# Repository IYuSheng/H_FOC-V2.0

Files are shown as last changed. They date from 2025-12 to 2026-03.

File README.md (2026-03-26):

# H_FOC V2.0

<p align="center">
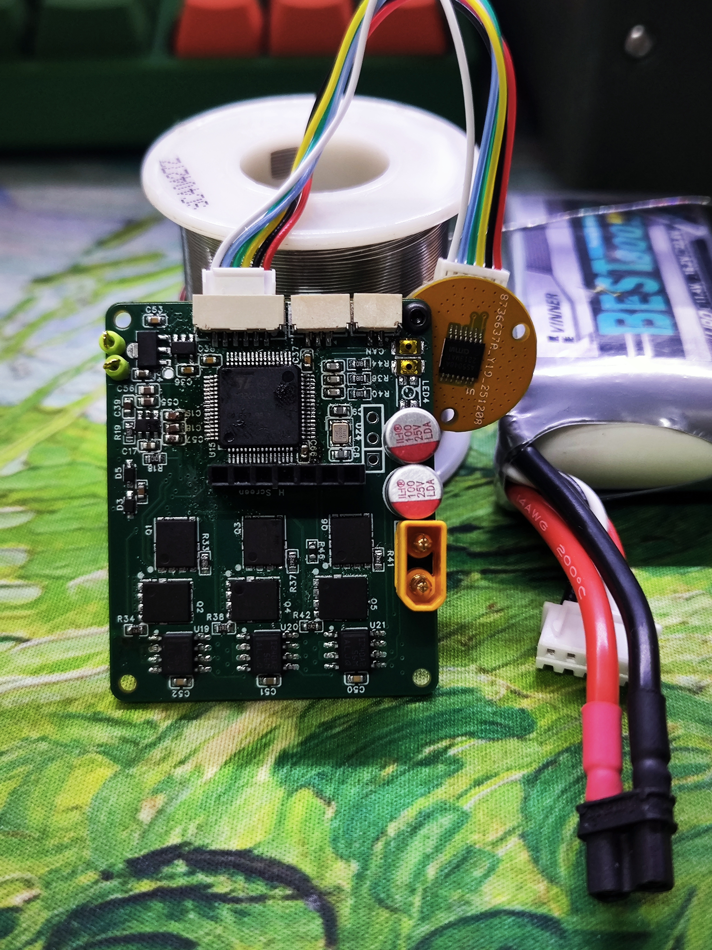
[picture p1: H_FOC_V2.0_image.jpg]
H_FOC V2.0 board render
  
</p>

<p align="center">
  面向机器人关节驱动与双关节机械臂实验平台的软硬件一体化项目
</p>

<p align="center">
  
  
  
  
</p>

<p align="center">
  <a href="#项目概览">项目概览</a> |
  <a href="#系统架构">系统架构</a> |
  <a href="#快速开始">快速开始</a> |
  <a href="#通信协议">通信协议</a> |
  <a href="#设计资料">设计资料</a>
</p>

## 项目概览

`H_FOC V2.0` 面向机器人关节电机控制场景，核心目标是构建一块可用于关节驱动、实验验证和上位机联调的 FOC 控制板，并围绕它形成一套可持续迭代的软件工具链。

从当前仓库内容来看，这个项目已经覆盖了以下几条主线：

- 基于 `STM32G431RBT6` 的电机控制固件
- 基于 `AS5048A` 的编码器闭环采样
- 基于 `CAN FD` 的主从关节通信
- 面向双关节平面机械臂的运动学、示教与重力补偿
- 基于 `Qt6` 的桌面上位机
- PCB 资料、交互式 BOM、结构模型和芯片手册归档

## 亮点特性

- `20 kHz` PWM / 电流环控制，使用 `CORDIC`、`FMAC` 等 STM32G4 外设辅助运算。
- 编码器经 `SPI2` 读取角度，并在固件中完成机械角、电角度、速度和加速度观测。
- 内置过压、欠压、过流、过温、编码器异常、采样异常等保护状态机。
- 支持 `CAN FD` 状态上报与控制指令下发，协议字段简洁清晰，适合继续扩展。
- MIT 风格控制命令已接入：目标电流、目标角度、目标速度、目标加速度、目标 jerk、刚度、阻尼、控制模式。
- `S-curve` 轨迹规划已在固件侧接入，`trapezoidal` 模式接口已预留。
- Qt 上位机已经实现双关节机械臂工作区显示、点击示教、控制模式切换和实时状态展示。
- 仓库同时保留了结构设计、BOM 和芯片资料，适合继续做硬件迭代和文档整理。

## 仓库结构

```text
H_FOC_V2.0/
|-- Code/
|   |-- H_FOC V2.1/                # 历史固件版本
|   |-- H_FOC V2.2/                # 当前主固件版本
|   |-- H_FOC_Robot_App/           # Qt6 机器人上位机
|   |-- control.py                 # 串口版控制/可视化脚本
|   `-- control_can.py             # CAN FD 版控制/可视化脚本
|-- Control_GUI/
|   `-- arm_ui/
|       `-- main.py                # RC + Serial + CAN(SLCAN) 调试界面
|-- 结构/                           # SolidWorks 结构文件
|-- 相关芯片手册/                    # 芯片资料归档
|-- InteractiveBOM_PCB1_2025-12-18.html
|-- H_FOC V2.0.docx
|-- H_FOC_V2.0_image.jpg
`-- README.md
```

### 模块索引

| 模块 | 路径 | 说明 |
| --- | --- | --- |
| 主固件 | [`Code/H_FOC V2.2`](./Code/H_FOC%20V2.2) | 推荐从这里开始，包含 FOC、编码器、CAN FD、轨迹规划与保护逻辑 |
| 旧版固件 | [`Code/H_FOC V2.1`](./Code/H_FOC%20V2.1) | 保留的历史版本，可用于对照差异 |
| Qt 上位机 | [`Code/H_FOC_Robot_App/H_FOC_Robot_App`](./Code/H_FOC_Robot_App/H_FOC_Robot_App) | 双关节机械臂界面、CAN FD 通信、运动学与控制参数配置 |
| Python CAN 工具 | [`Code/control_can.py`](./Code/control_can.py) | CAN FD 监控、示教、仿真与控制 |
| Python 串口工具 | [`Code/control.py`](./Code/control.py) | 基于 UART 文本协议的控制与可视化 |
| 调试 GUI | [`Control_GUI/arm_ui/main.py`](./Control_GUI/arm_ui/main.py) | RC + Serial + SLCAN 联调工具 |
| 交互式 BOM | [`InteractiveBOM_PCB1_2025-12-18.html`](./InteractiveBOM_PCB1_2025-12-18.html) | 浏览器可直接打开 |
| 结构模型 | [`结构`](./结构) | 结构件、座子和测试台架模型 |
| 芯片资料 | [`相关芯片手册`](./相关芯片手册) | MCU、编码器等资料归档 |
| 设计说明 | [`H_FOC V2.0.docx`](./H_FOC%20V2.0.docx) | 板卡引脚与说明文档 |

## 固件概览

主固件位于 [`Code/H_FOC V2.2`](./Code/H_FOC%20V2.2)，从代码可以确认它的关键特征如下：

| 项目 | 内容 |
| --- | --- |
| 主控 MCU | `STM32G431RBT6` |
| 系统主频 | `170 MHz` |
| PWM 频率 | `20 kHz` |
| 编码器 | `AS5048A` |
| 总线 | `FDCAN1` |
| 调试串口 | `USART3` |
| 工程文件 | `MDK-ARM/H_FOC V2.0.uvprojx` |
| CubeMX 文件 | `H_FOC V2.0.ioc` |

默认参数中可读到以下安全和控制边界：

| 项目 | 默认值 |
| --- | --- |
| 母线电压限制 | `30.0 V` |
| 最大相电流 | `5.5 A` |
| 欠压阈值 | `9.0 V` |
| 过温阈值 | `60.0 °C` |
| 电机极对数 | `11` |
| 机械角度保护范围 | `-170° ~ 70°` |

### 固件主入口

- 参数配置：[`Code/H_FOC V2.2/APP/Config.h`](./Code/H_FOC%20V2.2/APP/Config.h)
- 系统入口：[`Code/H_FOC V2.2/Core/Src/main.c`](./Code/H_FOC%20V2.2/Core/Src/main.c)
- 初始化：[`Code/H_FOC V2.2/APP/FOC_Init.c`](./Code/H_FOC%20V2.2/APP/FOC_Init.c)
- 编码器驱动：[`Code/H_FOC V2.2/APP/foc_encoder.c`](./Code/H_FOC%20V2.2/APP/foc_encoder.c)
- 控制主逻辑：[`Code/H_FOC V2.2/APP/foc_control.c`](./Code/H_FOC%20V2.2/APP/foc_control.c)
- 通信封装：[`Code/H_FOC V2.2/MID/foc_communication.c`](./Code/H_FOC%20V2.2/MID/foc_communication.c)
- CAN FD 协议：[`Code/H_FOC V2.2/Core/Inc/fdcan.h`](./Code/H_FOC%20V2.2/Core/Inc/fdcan.h)

## 上位机与工具链

### Qt6 机器人上位机

路径：[`Code/H_FOC_Robot_App/H_FOC_Robot_App`](./Code/H_FOC_Robot_App/H_FOC_Robot_App)

当前功能：

- `Qt 6.5+`
- `Qt Widgets + Qt SerialPort`
- 双关节机械臂工作区可视化
- 点击画布设置末端目标点
- 实时显示目标位置、当前姿态、关节角速度、电流与通信状态
- 提供 `normal / trapezoidal / s_curve` 控制模式选项
- 当前固件侧重点接入的是 `normal / s_curve`
- 可配置刚度、阻尼、速度、加速度、jerk

关键配置入口：

- [`Code/H_FOC_Robot_App/H_FOC_Robot_App/core/appconfig.h`](./Code/H_FOC_Robot_App/H_FOC_Robot_App/core/appconfig.h)

## 通信协议

### CAN FD 协议摘要

当前固件与上位机使用的协议要点如下：

- 标准 `11-bit CAN ID`
- ID 组织方式：`(src << 8) | (dst << 4) | type`
- 主节点 ID：`0`
- 默认关节节点：`1 / 2`
- 广播地址：`0x0F`
- 仲裁段速率：`1 Mbps`
- 数据段速率：`2 Mbps`
- 定点缩放比例：`1e-5`

### 状态帧 `STATUS`

| 字段 | 类型 |
| --- | --- |
| position | `int32` |
| velocity | `int32` |
| current | `int32` |
| temperature | `int32` |
| acceleration | `int32` |

### 控制帧 `CONTROL`

| 字段 | 类型 |
| --- | --- |
| target_current | `int32` |
| target_angle | `int32` |
| target_velocity | `int32` |
| target_acceleration | `int32` |
| target_jerk | `int32` |
| stiffness | `int32` |
| damping | `int32` |
| control_mode | `uint8` |

### UART 文本命令

固件串口解析逻辑当前可识别以下文本命令：

- `target_position:<float>`
- `target_speed:<float>`
- `current_q:<float>`
- `target_q:<float>`

这使得在没有 CAN FD 的情况下，仍然可以通过串口完成基础联调。

## 快速开始

### 环境准备

建议准备以下工具链：

- `Keil MDK` 或可兼容当前工程的 ARM 编译环境
- `STM32CubeMX`，用于查看或再生成外设配置
- `Qt 6.5+`
- CAN FD 转接设备，或支持 `SLCAN` 的串口桥接设备

### 固件构建

1. 打开 [`Code/H_FOC V2.2/MDK-ARM/H_FOC V2.0.uvprojx`](./Code/H_FOC%20V2.2/MDK-ARM/H_FOC%20V2.0.uvprojx)
2. 根据硬件修改 [`Code/H_FOC V2.2/APP/Config.h`](./Code/H_FOC%20V2.2/APP/Config.h)
3. 编译并下载到 `STM32G431RBT6`
4. 如需查看外设配置，可打开 [`Code/H_FOC V2.2/H_FOC V2.0.ioc`](./Code/H_FOC%20V2.2/H_FOC%20V2.0.ioc)

### Qt 上位机构建

```powershell
cd "Code/H_FOC_Robot_App/H_FOC_Robot_App"
cmake -S . -B build
cmake --build build --config Release
```

依赖：

- `Qt 6.5+`
- `Qt SerialPort`

## 配置入口

如果你要改默认参数，通常会从这些文件开始：

| 场景 | 文件 |
| --- | --- |
| 固件控制参数 | [`Code/H_FOC V2.2/APP/Config.h`](./Code/H_FOC%20V2.2/APP/Config.h) |
| Qt 上位机默认通道和控制参数 | [`Code/H_FOC_Robot_App/H_FOC_Robot_App/core/appconfig.h`](./Code/H_FOC_Robot_App/H_FOC_Robot_App/core/appconfig.h) |

## 设计资料

保留了较完整的研发资料入口：

- 板卡外观图：[`H_FOC_V2.0_image.jpg`](./H_FOC_V2.0_image.jpg)
- 交互式 BOM：[`InteractiveBOM_PCB1_2025-12-18.html`](./InteractiveBOM_PCB1_2025-12-18.html)
- 结构模型：[`结构`](./结构)
- 芯片手册：[`相关芯片手册`](./相关芯片手册)
- 设计说明：[`H_FOC V2.0.docx`](./H_FOC%20V2.0.docx)

<details>
<summary>展开查看板卡主要引脚摘要</summary>

- ADC 采样：`PC0 / PC1 / PC2 / PC3` = `VA / VB / VC / VBUS`
- 电流采样：`PA0 / PA1 / PA2` = `IA / IB / IC`
- 温度采样：`PC4`
- 三相驱动高端：`PC6 / PC7 / PC8`
- 三相驱动低端：`PC10 / PC11 / PC12`
- 编码器：`PB12 / PB13 / PB14 / PB15`
- 调试 DAC：`PA4 / PA5`
- 调试串口：`PB10 / PB11`
- 屏幕接口：`PB3 / PB5 / PB6 / PB7 / PA15`
- CAN：`PB8 / PB9`
- 按键：`PA8 / PA9`
- 三色灯：`PB0 / PB1 / PB2`

</details>

## 安全提示

涉及电机、功率板和机械臂时，建议至少注意以下几点：

- 首次上电时使用受限电源或降低电压。
- 先确认编码器方向、零位和关节限位是否正确。
- 在低速、空载或脱开机械结构的状态下先验证闭环。
- 修改电流、电压和刚度参数前，先确认硬件承受范围。
- 在真实机械臂联调时，避免直接在满量程和无软限位保护下运行。

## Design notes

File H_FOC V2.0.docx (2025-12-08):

# H_FOC V2.0

## 1. 引脚定义

(1) ADC采样

PC0、PC1、PC2、PC3 : VA、VB、VC、VBUS

PA0、PA1、PA2 : IA、IB、IC

PC4 : R_Temperature

(2) 驱动

高端:PC6、PC7、PC8 : HA、HB、HC

低端:PC10、PC11、PC12 : LA、LB、LC

(3) 编码器

PB12、PB13、PB14、PB15 : Encoder_CS、Encoder_SCK、Encoder_MISO、Encoder_MOSI

(4) 调试DAC

PA4、PA5 : DAC1、DAC2

(5) 调试串口

PB10、PB11 : UART3_TX、UART_RX

(6) 屏幕

PB3、PB5、PB6、PB7、PA15 : Screen_SCK、Screen_MOSI、Screen_DC、Screen_RES、Screen_CS

(7) CAN通讯

PB8、PB9 : FDCAN_RX、FDCAN_TX

(8) 按键

PA8、PA9 : KEY_1、KEY_2

(9) 三色灯

PB0、PB1、PB2 : Blue、Green、Red

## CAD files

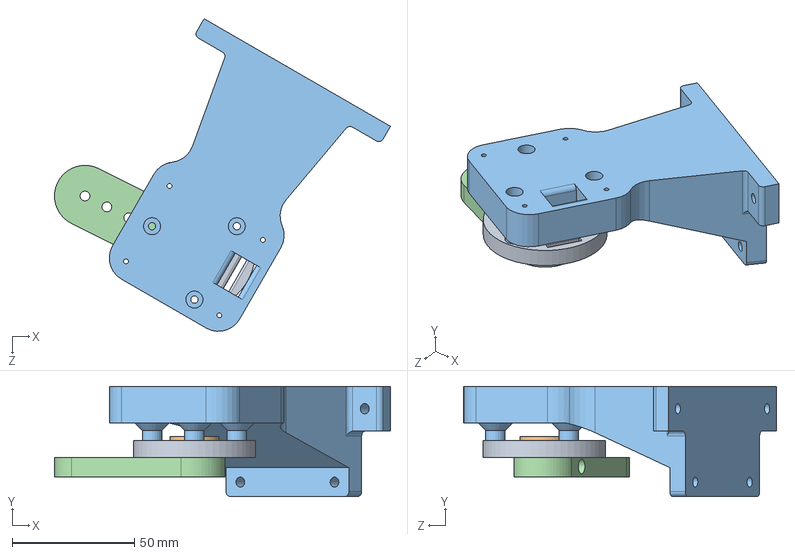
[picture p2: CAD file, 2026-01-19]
结构/电机座子/电机座子.SLDASM
137.4 x 45.0 x 127.8 mm
电机转接器
编码器板
电机驱动板连接器
测试负载连杆

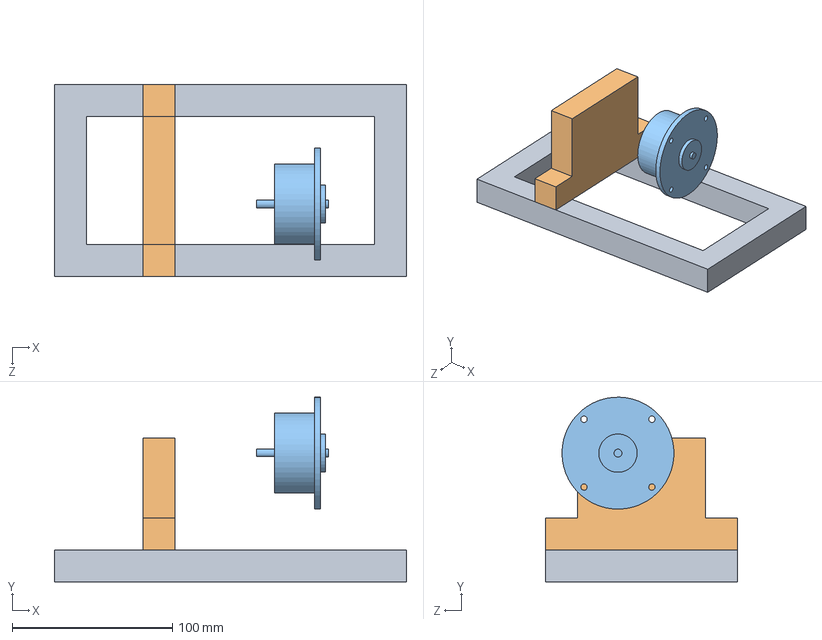
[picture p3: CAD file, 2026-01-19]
结构/电机测试台架/测试台架装配体.SLDASM
220.0 x 115.4 x 120.0 mm
台架底座
电机支架底座
磁粉制动器

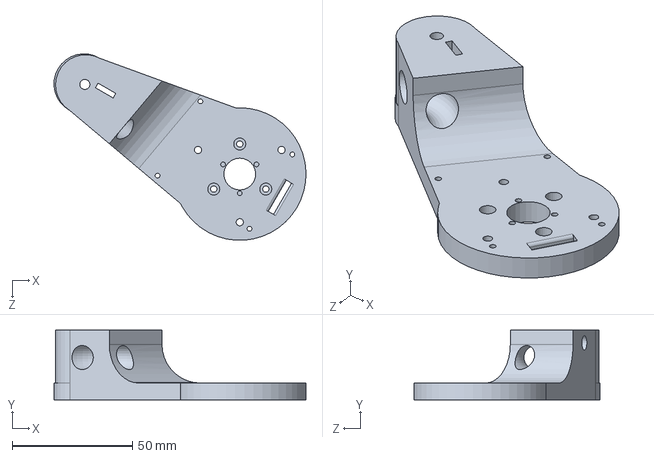
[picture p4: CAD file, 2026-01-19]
结构/电机座子/第二电机测试座.SLDPRT
104.6 x 29.0 x 77.3 mm

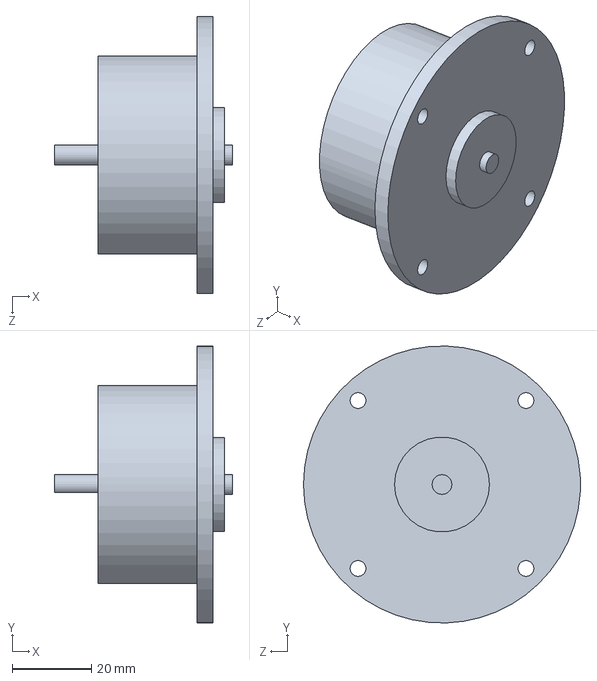
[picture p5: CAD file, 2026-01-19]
结构/电机测试台架/磁粉制动器.SLDPRT
45.0 x 70.0 x 70.0 mm

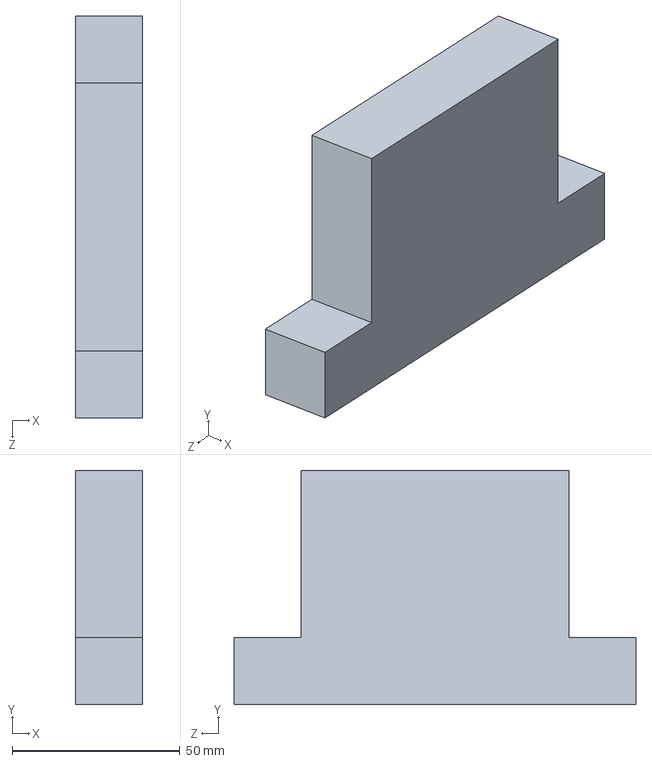
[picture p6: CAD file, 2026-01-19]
结构/电机测试台架/电机支架底座.SLDPRT
20.0 x 70.0 x 120.0 mm

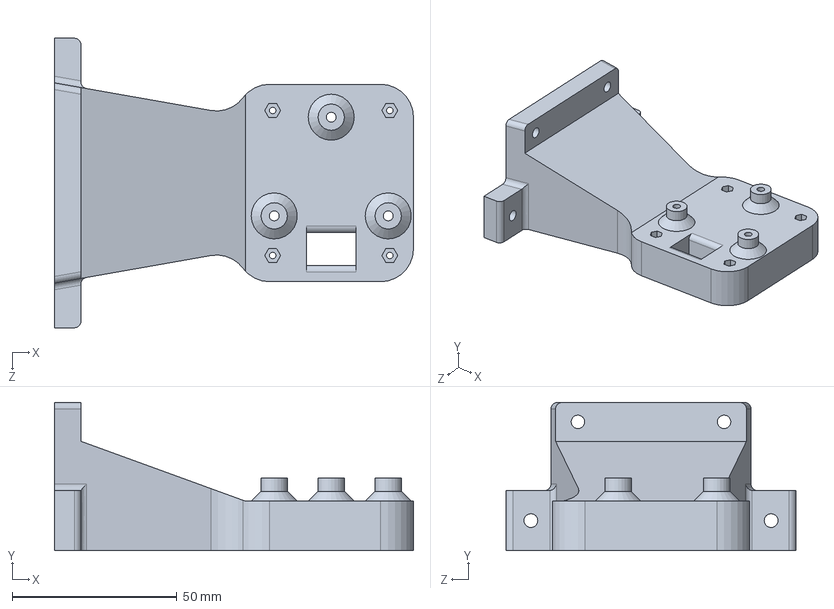
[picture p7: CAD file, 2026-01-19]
结构/电机座子/电机驱动板连接器.SLDPRT
109.1 x 45.0 x 88.0 mm

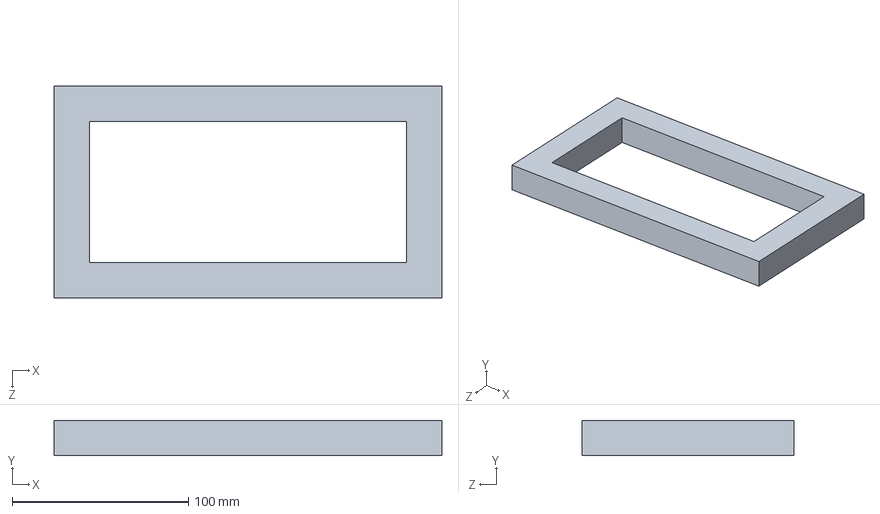
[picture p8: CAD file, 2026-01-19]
结构/电机测试台架/台架底座.SLDPRT
220.0 x 20.0 x 119.9 mm

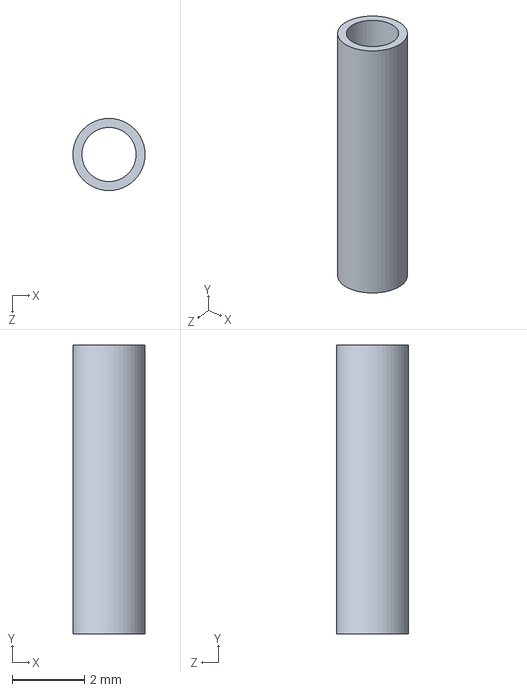
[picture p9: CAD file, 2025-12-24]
结构/电机座子/驱动器支撑柱.SLDPRT
2.00 x 8.00 x 2.00 mm

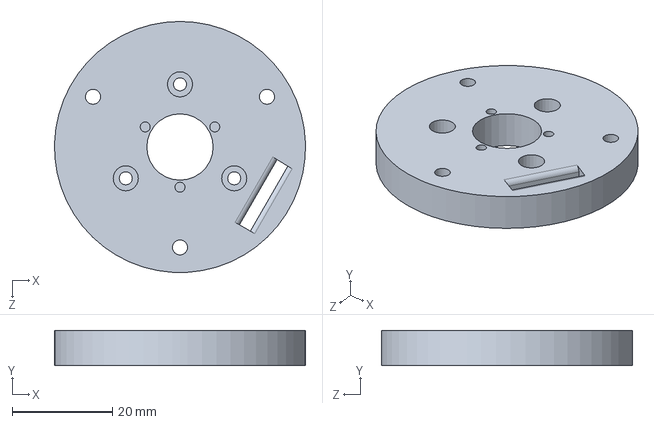
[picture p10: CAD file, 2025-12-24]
结构/电机座子/电机转接器.SLDPRT
50.0 x 7.00 x 50.0 mm

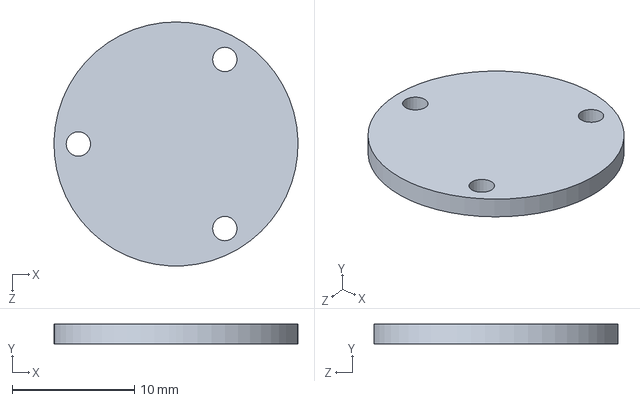
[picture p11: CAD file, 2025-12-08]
结构/电机座子/编码器板.SLDPRT
20.0 x 1.60 x 20.0 mm

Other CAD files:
结构/电机座子/测试负载连杆.SLDPRT

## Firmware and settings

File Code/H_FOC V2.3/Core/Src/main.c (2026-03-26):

#include "main.h"

Motor_Control_t motor_ctrl = {
    .foc_state =  FOC_STATE_INIT,
    .fault_type = MOTOR_FAULT_NONE,
    .temp_max = OVER_TEMPERATURE_THRESH,    // 过温阈值
    .vbus_max = VOLTAGE_LIMIT,              // 过压阈值
    .vbus_min = UNDER_VOLTAGE_THRESH,       // 欠压阈值
    .current_max = CURRENT_LIMIT,            // 过流阈值
    .angle_max = 90.0f,                      // 最大角度阈值（°/s）
    .angle_min = -190.0f                     // 最小角度阈值（°/s）
};

encoder_status_t enc_status; // 编码器状态变量

/**
  * @brief  The application entry point.
  * @retval int
  */
int main(void)
{
    // 初始化FOC相关外设
    FOC_Init();
    
    while(1)
    {
      /* ------------------ FOC状态机 ------------------ */
      switch(motor_ctrl.foc_state)
      {
        case FOC_STATE_INIT:  /* 电机初始化 */
          // 初始化编码器
          enc_status = encoder_init();
          foc_start_init();
          if(enc_status != ENCODER_STATUS_OK)
          {
            motor_ctrl.fault_type = FAULT_ENCODER;
            motor_ctrl.foc_state = FOC_STATE_FAULT;
          }
          // 开启FOC中断
          foc_start();
          motor_ctrl.foc_state = FOC_STATE_RUNNING;
          break;

        case FOC_STATE_RUNNING: /* 电机运行态 */
          // 设置外部控制参数
          foc_control_set();

          break;

        case FOC_STATE_FAULT: /* 电机故障态 */
          // 停止PWM输出
          bsp_pwm_stop();
          switch(motor_ctrl.fault_type)
          {
            case FAULT_OVER_VOLTAGE:
              debug_log("[ERROR] OVER_VOLTAGE");
              break;
              
            case FAULT_UNDER_VOLTAGE:
              debug_log("[ERROR] UNDER_VOLTAGE");
              break;
              
            case FAULT_OVER_CURRENT:
              debug_log("[ERROR] OVER_CURRENT");
              break;
              
            case FAULT_ENCODER:
              debug_log("[ERROR] ENCODER_ERROR");
              break;
              
            case FAULT_OVER_TEMPERATURE:
              debug_log("[ERROR] OVER_TEMPERATURE");
              break;

            case FAULT_I_SAMPLING_ERROR:
              debug_log("[ERROR] I_SAMPLING_ERROR");
              break;

            case FAULT_ENCODER_ANGLE:
              debug_log("[ERROR] ENCODER_ANGLE_ERROR");
              break;
              
            case MOTOR_FAULT_NONE:
              // 待添加恢复机制

              break;
            default:
              debug_log("[ERROR] UNKNOWN_ERROR");
              break;
          }
          motor_ctrl.foc_state = FOC_STATE_STOP;
          break;

        case FOC_STATE_STOP:  /* 电机停止态 */

          break;

        default:
          break;
      }

      /* --------------- 定时处理任务 --------------- */
      if(foc_task.task_update_vbus)
      {
        foc_task.task_update_vbus = 0;
        get_foc_bus_voltage();
      }
      if(foc_task.task_update_three_phase_voltage)
      {
        foc_task.task_update_three_phase_voltage = 0;
        update_Three_phase_voltage();
      }
      if(foc_task.task_update_temperature)
      {
        foc_task.task_update_temperature = 0;
        update_mosfet_temperature();
      }
      if(foc_task.task_sys_common)
      {
        foc_task.task_sys_common = 0;
        // CAN数据发送至主节点
        CAN_ReportStatus();
        // CAN数据处理
        CAN_Process();
        // foc打印调试任务
        foc_debug();
      }

      /* --------------- 异常状态检测 --------------- */
     if(foc_voltage_data.vbus > motor_ctrl.vbus_max)
     {
       motor_ctrl.fault_type = FAULT_OVER_VOLTAGE;
       if(motor_ctrl.foc_state == FOC_STATE_RUNNING)
       motor_ctrl.foc_state = FOC_STATE_FAULT;
     }
     if(foc_voltage_data.vbus < motor_ctrl.vbus_min)
     {
       motor_ctrl.fault_type = FAULT_UNDER_VOLTAGE;
       if(motor_ctrl.foc_state == FOC_STATE_RUNNING)
       motor_ctrl.foc_state = FOC_STATE_FAULT;
     }
     
     if(foc_current_data.ia > motor_ctrl.current_max
     || foc_current_data.ib > motor_ctrl.current_max
     || foc_current_data.ic > motor_ctrl.current_max)
     {
       motor_ctrl.fault_type = FAULT_OVER_CURRENT;
       if(motor_ctrl.foc_state == FOC_STATE_RUNNING)
       motor_ctrl.foc_state = FOC_STATE_FAULT;
     }
     if(foc_voltage_data.temp > motor_ctrl.temp_max)
     {
       motor_ctrl.fault_type = FAULT_OVER_TEMPERATURE;
       if(motor_ctrl.foc_state == FOC_STATE_RUNNING)
       motor_ctrl.foc_state = FOC_STATE_FAULT;
     }
     if(foc_current_data.ia + foc_current_data.ib + foc_current_data.ic > 10.0f
     || foc_current_data.ia + foc_current_data.ib + foc_current_data.ic < -10.0f)
     {
       motor_ctrl.fault_type = FAULT_I_SAMPLING_ERROR;
       if(motor_ctrl.foc_state == FOC_STATE_RUNNING)
       motor_ctrl.foc_state = FOC_STATE_FAULT;
     }
    //  if(encoder_data.mechanical_angle > motor_ctrl.angle_max || encoder_data.mechanical_angle < motor_ctrl.angle_min)
    //  {
    //    motor_ctrl.fault_type = FAULT_ENCODER_ANGLE;
    //    if(motor_ctrl.foc_state == FOC_STATE_RUNNING)
    //    motor_ctrl.foc_state = FOC_STATE_FAULT;
    //  }
    }
}

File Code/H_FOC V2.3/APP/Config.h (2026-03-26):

#ifndef __CONFIG_H
#define __CONFIG_H

#include <arm_math.h>

// --------------------------- 模式选项 --------------------------
#define DEBUG_MODE  1     // 打开仿真波形打印

// -------------------------- 电源与硬件限制 --------------------------
#define VOLTAGE_LIMIT           30.0f   // 直流母线电压限制 (V)
#define CURRENT_LIMIT           5.5f    // 最大相电流限制 (A)
#define UNDER_VOLTAGE_THRESH    9.0f   // 欠压保护阈值 (V)
#define OVER_TEMPERATURE_THRESH 60.0f   // 过温保护阈值 (摄氏度)

// -------------------------- 电机参数 -------------------------- 
#define MOTOR_POLE_PAIRS     11       // 电机极对数
#define MOTOR_RESISTANCE     0.338f    // 相电阻 (欧姆)
#define MOTOR_INDUCTANCE     0.000113f  // 相电感 (H)
#define MOTOR_INDUCTANCE_Lq  0.000140f // q轴电感 (H)
#define MOTOR_INDUCTANCE_Ld  0.000086f // d轴电感 (H)
#define MOTOR_FLUX_LINKAGE   0.002481f   // 磁链 (Wb)

#define MOTOR_LOW             -53.7f * PI / 180.0f   // 物理层面上的电机最低位置

// -------------------------- FOC控制参数 --------------------------
#define PWM_FREQ            20000.0f   // PWM频率 (Hz)，需与定时器配置匹配
#define HALF_PWM_FREQ       PWM_FREQ * 0.5f   // PWM频率 (Hz)，需与定时器配置匹配
#define PWM_PERIOD_S        1.0f / PWM_FREQ  // PWM周期（单位：s），与PWM_FREQ对应：T = 1/F
#define SVPWM_VOLT_COEF     (2.0f / sqrtf(3.0f)) // SVPWM基本矢量幅值系数（母线电压相关，固定值）
#define DEAD_TIME_S         (170e-9f)       // 死区时间 170ns

// -------------------------- PI调节器参数 --------------------------
// 电流环PI
#define CURRENT_LOOP_COUNT        PWM_FREQ
#define CURRENT_LOOP_DT           (1.0f / CURRENT_LOOP_COUNT)  // 电流环调用周期 (单位：s)
#define I_D_P_GAIN                (MOTOR_INDUCTANCE_Ld / (3 * PWM_PERIOD_S)) //Kp = Ld / (3*Ts)
#define I_Q_P_GAIN                (MOTOR_INDUCTANCE_Lq / (3 * PWM_PERIOD_S)) //Kp = Lq / (3*Ts)
#define I_I_GAIN                  ((MOTOR_RESISTANCE / (3 * PWM_PERIOD_S)) * CURRENT_LOOP_DT) //KI = (Rs / (3*Ts)) * Ts(减小一个乘法)
#define CURRENT_LOOP_BANDWIDTH    (I_Q_P_GAIN / (2 * PI * MOTOR_INDUCTANCE_Lq))      // 电流环带宽 (Hz) 1061
#define I_I_LIMIT                 0.2f

// 速度环PI
#define SPEED_LOOP_TIME     1000.0f
#define SPEED_LOOP_COUNT    (PWM_FREQ / SPEED_LOOP_TIME)
#define SPEED_LOOP_DT       (1.0f / SPEED_LOOP_TIME)      // 速度环调用周期 (单位：s)
#define SPEED_P_GAIN        0.0002f
#define SPEED_I             0.00001f
#define SPEED_I_GAIN        (SPEED_I * SPEED_LOOP_DT) //KI = Ki * Ts(减小一个乘法)
#define SPEED_I_LIMIT       0.05f
#define SPEED_OUT_LIMIT     1.0f

// 位置环PID
#define POSITION_LOOP_TIME   1000.0f  // 位置环调用频率 (1000Hz)
#define POSITION_LOOP_COUNT  (PWM_FREQ / POSITION_LOOP_TIME)
#define POSITION_LOOP_DT    (1.0f / POSITION_LOOP_TIME) // 位置环调用周期 (单位：s)
#define POSITION_P_GAIN     0.1f
#define POSITION_I          0.0f
#define POSITION_I_GAIN     (POSITION_I * POSITION_LOOP_DT) //KI = Ki * Ts(减小一个乘法)
#define POSITION_D_GAIN     0.002f
#define POSITION_I_LIMIT    0.08f
#define POSITION_OUT_LIMIT  4.0f
#define POSITION_KV         8.0f
#define POSITION_W_MAX      600.0f

// -------------------------- 电流采样配置 --------------------------
#define ADC_REF_VOLTAGE     3.3f    // ADC参考电压 (V)
#define ADC_MAX_VALUE       4095.0f    // ADC分辨率 (例如：12位ADC为4095，0-4095)
#define INA240_GAIN         50.0f   // 电流采样运放增益
#define V_REF               1.65f    // REF1 引脚电压3.3V，单位：V
#define R_Current           0.006f    // 采样电阻阻值

// -------------------------- 电压采样配置 --------------------------
#define R_Voaltage_1  20.0f   // 20KΩ
#define R_Voaltage_2  2.2f    // 2.2KΩ

// -------------------------- 常用常量及中间变量定义 --------------------------
#define _PI         PI
#define _2PI        (2.0f * PI)
#define _PI_2       (PI / 2.0f)
#define _2_PI       (1.0f / (2.0f * PI))
#define _60_angle   (2.0f * PI / 6.0f)  // 60度对应的弧度
#define _SQRT3      1.732050807568877f
#define _SQRT3_2    0.866025403784439f  // sqrt(3)/2
#define _1_SQRT3    0.577350269189626f  // 1/sqrt(3)
#define _2_SQRT3    1.154700538379252f  // 2/sqrt(3)
#define RPM_TO_PI   (_2PI / 60.0f)        // RPM转换为弧度系数 (RPM * 2*PI / 60)
#define RPM_TO_DEGREE   (360.0f / 60.0f)   // RPM转换为度数系数
#define SPEED_FACTOR (_2PI / 60.0f * MOTOR_POLE_PAIRS) // 速度转换系数 (机械转速rpm → 电角速度rad/s)
#define SPEED_FACTOR360 (360.0f / 60.0f * MOTOR_POLE_PAIRS) // 速度转换系数 (机械转速rpm → 电角速度°/s)
#define RAD_TO_DEG  (180.0f / PI)
#define FACTOR       (_SQRT3 / PWM_FREQ)  // SVPWM时间中间计算系数
#define PWM_PERIOD        ((170000000.0f / (2.0f * PWM_FREQ)) - 1)  // PWM周期计数值 (TIM时钟频率需根据实际配置调整)
#define PWM_FREQ_PERIOD (PWM_FREQ * PWM_PERIOD) // SVPWM时间转比较值中间系数
#define EPS_F       1e-6f     // 浮点数精度


// -------------------------- 故障状态定义 --------------------------
typedef enum
{
  MOTOR_FAULT_NONE,       // 无故障
  FAULT_OVER_CURRENT,     // 过流
  FAULT_OVER_VOLTAGE,     // 过压
  FAULT_UNDER_VOLTAGE,    // 欠压
  FAULT_OVER_TEMPERATURE, // 过温
  FAULT_ENCODER,          // 编码器故障
  FAULT_ENCODER_ANGLE,    // 编码器角度超限制
  FAULT_I_SAMPLING_ERROR  // 电流采样错误
} FOC_FAULT;
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

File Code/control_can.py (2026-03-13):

#!/usr/bin/env python3
# -*- coding: utf-8 -*-
"""
Dual-joint arm real-time monitor/control over CAN FD.

Protocol mapping follows current Core/Inc/fdcan.h:
- CAN ID (11-bit): (src << 8) | (dst << 4) | msg_type
- STATUS frame payload: 5 x int32_t
- CONTROL frame payload: 7 x int32_t + 1 x uint8_t
"""

import argparse
import math
import struct
import threading
import time
from dataclasses import dataclass
from typing import Dict, Optional, Tuple

try:
    # 优先使用 PyQt5；若本机未安装，则兼容 PySide6（API 基本一致）
    from PyQt5 import QtCore, QtWidgets, QtGui
except Exception:
    from PySide6 import QtCore, QtWidgets, QtGui

try:
    import can
except Exception:
    can = None


# ==================== Config ====================
class Config:
    # CAN FD transport
    CAN_INTERFACE = "slcan"
    CAN_CHANNEL = "COM21"
    SLCAN_TTY_BAUDRATE = 4_000_000
    SLCAN_TIMEOUT_SEC = 0.0
    
    # CAN FD 波特率配置（必须与你的STM32配置匹配）
    # 仲裁段: 1Mbps (与你的C代码 CAN_NOMINAL_PRESCALER等匹配)
    CAN_NOMINAL_BITRATE = 1_000_000
    # 数据段: 2Mbps (与你的C代码 CAN_DATA_PRESCALER等匹配)
    CAN_DATA_BITRATE = 2_000_000
    
    ENABLE_CONTROL_TX = True

    # Node IDs
    MASTER_ID = 0
    MOTOR1_ID = 1
    MOTOR2_ID = 2
    BROADCAST_ID = 0x0F

    # Message types (必须与你的fdcan.h一致)
    MSG_TYPE_STATUS = 0x0
    MSG_TYPE_CONTROL = 0x1

    # Control mode (必须匹配 fdcan.h)
    CONTROL_MODE_NORMAL = 0
    CONTROL_MODE_TRAPEZOIDAL = 1
    CONTROL_MODE_S_CURVE = 2
    CONTROL_MODE = CONTROL_MODE_S_CURVE

    # 定点数缩放比例（必须匹配你的STM32代码）
    SCALE_32 = 1e-5  # 32位定点数缩放

    # MIT控制参数默认值与界面范围
    CMD_STIFFNESS_DEFAULT_J1 = 0.6
    CMD_STIFFNESS_DEFAULT_J2 = 0.1
    CMD_STIFFNESS_MIN = 0.0
    CMD_STIFFNESS_MAX = 1.0
    CMD_DAMPING_DEFAULT_J1 = 0.015
    CMD_DAMPING_DEFAULT_J2 = 0.001
    CMD_DAMPING_MIN = 0.0
    CMD_DAMPING_MAX = 0.02
    CMD_DAMPING_MAX_J1 = 0.02
    CMD_DAMPING_MAX_J2 = 0.005

    # 轨迹模式参数（梯形 / S 曲线）
    PROFILE_VELOCITY_MIN_DEG_S = 5.0
    PROFILE_VELOCITY_MAX_DEG_S = 300.0
    PROFILE_VELOCITY_DEFAULT_DEG_S = 90.0
    PROFILE_ACCEL_MIN_DEG_S2 = 10.0
    PROFILE_ACCEL_MAX_DEG_S2 = 20_000.0
    PROFILE_ACCEL_DEFAULT_DEG_S2 = 2_000.0
    PROFILE_JERK_MIN_DEG_S3 = 10.0
    PROFILE_JERK_MAX_DEG_S3 = 50_000.0
    PROFILE_JERK_DEFAULT_DEG_S3 = 5_000.0

    # 重力补偿前馈（单位：A）
    GRAVITY_FF_J1 = 3.1
    GRAVITY_FF_J2 = 0.38
    GRAVITY_OFFSET_J1_DEG = -53.7
    GRAVITY_OFFSET_J2_DEG = 172.5

    # Loop and timeout
    LOOP_DT = 0.001
    RX_STALE_SEC = 0.05
    RX_THREAD_RECV_TIMEOUT_SEC = 0.001
    UI_UPDATE_MS = 50

    # Kinematics / controller
    L1, L2 = 0.07748, 0.0625
    ZERO1, ZERO2 = -53.7, 172.5
    KPX, KDX = 10.0, 1.0
    KPY, KDY = 10.0, 1.0
    F_MAX, IQ_MAX, KT = 20.0, 8.0, 0.095
    XLIM, YLIM = (-0.15, 0.15), (-0.18, 0.05)
    # 关节1角度限制（deg）
    J1_MIN_DEG, J1_MAX_DEG = -170.0, 70.0
    # 手动关节控制参数
    MANUAL_SPEED_MIN_DEG_S = 5.0
    MANUAL_SPEED_MAX_DEG_S = 300.0
    J2_MANUAL_MIN_DEG, J2_MANUAL_MAX_DEG = -360.0, 360.0


@dataclass
class Joint:
    th1: float = 0.0
    w1: float = 0.0
    th2: float = 0.0
    w2: float = 0.0


@dataclass
class Cart:
    x: float = 0.0
    y: float = 0.0
    vx: float = 0.0
    vy: float = 0.0


@dataclass
class Ctrl:
    fx: float = 0.0
    fy: float = 0.0
    iq1: float = 0.0
    iq2: float = 0.0
    grav1: float = 0.0
    grav2: float = 0.0


@dataclass
class MotorStatus:
    th: float = 0.0
    w: float = 0.0
    cur: float = 0.0
    temp: float = 0.0
    acc: float = 0.0
    status: int = 0
    error: int = 0
    t_rx: float = 0.0


# ==================== Math / protocol helpers ====================
def clamp(v: float, lo: float, hi: float) -> float:
    return lo if v < lo else hi if v > hi else v


def can_id_make(src: int, dst: int, msg_type: int) -> int:
    """生成CAN ID: (src << 8) | (dst << 4) | msg_type"""
    return ((src & 0x0F) << 8) | ((dst & 0x0F) << 4) | (msg_type & 0x0F)


def can_id_get_src(can_id: int) -> int:
    return (can_id >> 8) & 0x0F


def can_id_get_dst(can_id: int) -> int:
    return (can_id >> 4) & 0x0F


def can_id_get_type(can_id: int) -> int:
    return can_id & 0x0F


def float_to_fix32(v: float) -> int:
    """32位定点数转换"""
    raw = int(v / Config.SCALE_32)
    return max(-2147483648, min(2147483647, raw))


def fix32_to_float(v: int) -> float:
    return float(v) * Config.SCALE_32


def control_mode_name(mode: int) -> str:
    if mode == Config.CONTROL_MODE_NORMAL:
        return "normal"
    if mode == Config.CONTROL_MODE_TRAPEZOIDAL:
        return "trapezoidal"
    if mode == Config.CONTROL_MODE_S_CURVE:
        return "s_curve"
    return f"unknown({mode})"


# ==================== Kinematics & controller ====================
def kinematics(j: Joint):
    t1 = math.radians(j.th1 - Config.ZERO1)
    t2 = math.radians(j.th2 - Config.ZERO2)
    t12 = t1 + t2
    s1, c1 = math.sin(t1), math.cos(t1)
    s12, c12 = math.sin(t12), math.cos(t12)

    x = -(Config.L1 * s1 + Config.L2 * s12)
    y = -(Config.L1 * c1 + Config.L2 * c12)

    j11 = -(Config.L1 * c1 + Config.L2 * c12)
    j12 = -(Config.L2 * c12)
    j21 = Config.L1 * s1 + Config.L2 * s12
    j22 = Config.L2 * s12

    d1, d2 = math.radians(j.w1), math.radians(j.w2)
    vx = j11 * d1 + j12 * d2
    vy = j21 * d1 + j22 * d2

    x1, y1 = -Config.L1 * s1, -Config.L1 * c1
    return Cart(x, y, vx, vy), (0.0, 0.0, x1, y1, x, y), (j11, j12, j21, j22)


def pd_control(c: Cart, tgt: Cart, jac: Tuple[float, float, float, float]):
    fx = Config.KPX * (tgt.x - c.x) + Config.KDX * (tgt.vx - c.vx)
    fy = Config.KPY * (tgt.y - c.y) + Config.KDY * (tgt.vy - c.vy)
    fx = clamp(fx, -Config.F_MAX, Config.F_MAX)
    fy = clamp(fy, -Config.F_MAX, Config.F_MAX)

    j11, j12, j21, j22 = jac
    tau1 = j11 * fx + j21 * fy
    tau2 = j12 * fx + j22 * fy

    iq1 = clamp(tau1 / Config.KT, -Config.IQ_MAX, Config.IQ_MAX)
    iq2 = clamp(tau2 / Config.KT, -Config.IQ_MAX, Config.IQ_MAX)
    return Ctrl(fx, fy, iq1, iq2)


def gravity_compensation_currents(j: Joint) -> Tuple[float, float]:
    """
    使用当前机械角计算两个关节的重力补偿前馈电流。
    J1 采用带机械零点偏置的绝对姿态正弦补偿；
    J2 采用第二连杆带偏置后的绝对姿态正弦补偿，能够随机构姿态变化。
    """
    theta1 = math.radians(j.th1 - Config.GRAVITY_OFFSET_J1_DEG)
    theta2 = math.radians(j.th2 - Config.GRAVITY_OFFSET_J2_DEG)
    iq_grav1 = Config.GRAVITY_FF_J1 * math.sin(theta1)
    iq_grav2 = Config.GRAVITY_FF_J2 * math.sin(theta1 + theta2)
    return iq_grav1, iq_grav2


def _wrap_deg_err(err_deg: float) -> float:
    """把角度误差约束到[-180, 180]，用于逆解分支选择。"""
    while err_deg > 180.0:
        err_deg -= 360.0
    while err_deg < -180.0:
        err_deg += 360.0
    return err_deg


def _unwrap_deg_to_ref(angle_deg: float, ref_deg: float) -> float:
    """
    将角度映射到最接近ref_deg的等效角，避免跨±180产生大跳变。
    例如：ref=179, angle=-179 -> 输出181（而不是-179）。
    """
    return ref_deg + _wrap_deg_err(angle_deg - ref_deg)
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

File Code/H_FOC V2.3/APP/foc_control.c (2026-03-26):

#include "foc_control.h"

SCurve_Planner_t g_pos_planner;

static inline void foc_open_loop_control(float target_speed, float target_outq);
static inline void foc_current_control(float target_d, float target_q);
static inline void foc_speed_control(float target_speed);
static inline void foc_position_control(float target_position);
static inline void foc_mit_control(void);
static inline void foc_current_control_hfi(float target_d, float target_q);

/**
 * @brief FOC打印调试信息
 */
void foc_debug(void)
{
    // debug_log("%.4f, %.4f, %.4f, %.4f, %.4f", foc_ctrl.target_q, foc_ctrl.abc_dq.current_q, foc_ctrl.abc_dq.current_d, encoder_data.electrical_speed, encoder_data.electrical_angle);
    // debug_log("%d, %d, %d", svpwm.pwm_a, svpwm.pwm_b, svpwm.pwm_c);
    // debug_log("%.4f, %.4f, %.4f, %.4f", foc_current_data.ia, foc_current_data.ib, foc_current_data.ic, foc_ctrl.angle);
    // debug_log("%.4f", foc_voltage_data.vbus);

    // 电磁转矩计算
    // foc_ctrl.Te = 1.5f * MOTOR_POLE_PAIRS * (MOTOR_FLUX_LINKAGE * foc_ctrl.abc_dq.current_q);
    // debug_log("%.4f", foc_ctrl.Te);

    // debug_log("%.4f, %.4f, %.4f", encoder_data.mechanical_angle, encoder_data.electrical_speed, encoder_data.mechanical_accsd);
    debug_log("%.4f, %.4f, %.4f", encoder_data.mechanical_angle, encoder_data.mechanical_speed, foc_ctrl.target_q);
    
    #if FOC_TEST_ENABLE // 扫频测试
    // q轴正弦波扫频输出
    static float sine_angle = 0.0f;
    const float amplitude = 0.1f;
    
    // 计算当前正弦值并设置到q轴输出
    foc_ctrl.target_q = amplitude * sinf(sine_angle);
    
    // 角度每次增加1度（弧度制）
    sine_angle += 0.0174533f;  // 1度 = π/180 弧度
    
    // 限制角度在0-2π范围内
    if(sine_angle >= 6.283185f) {
        sine_angle -= 6.283185f;
    }
    #endif
}

/**
 * @brief FOC初始化，锁定电机至零位
 */
void foc_start_init(void)
{   
    foc_ctrl.target_speed = 5.0f;   // 设置目标速度(°/s)
    foc_ctrl.out_q = 0.0f; // 设置q轴输出电压(开环用)
    foc_ctrl.out_d = 0.0f; // 设置d轴输出电压(开环用)
    foc_ctrl.target_q = 0.0f;  // 设置目标Q轴电流
    foc_ctrl.target_d = 0.0f;  // 设置目标D轴电流
    foc_ctrl.target_position = -25.0f;  // 设置目标位置
    // 初始化电流环PI参数
    foc_current_pi_init(I_D_P_GAIN, I_Q_P_GAIN, I_I_GAIN, I_I_LIMIT);
    // 初始化速度环PI参数
    foc_speed_pi_init(SPEED_P_GAIN, SPEED_I_GAIN, SPEED_I_LIMIT);
    // 初始化位置环PI参数
    foc_position_pi_init(POSITION_P_GAIN, POSITION_I_GAIN, POSITION_D_GAIN, POSITION_I_LIMIT);

    // 锁定电机至零位
    get_foc_bus_voltage(); // 获取电机母线电压
    debug_log("Vbus: %.2f V", foc_voltage_data.vbus);
    // 电流偏置校准 
    adc1_current_offset_calibrate();

    #if FOC_COGGING_COMPENSATION_ENABLE
    cogging_calibration_start();
    #endif

    #if FOC_RESONANCE_ENABLE
    resonance_test_trigger();
    #endif

    #if FOC_SHAPER_ENABLE
    // EI整型器 (固有频率 V Ts)
    // ei_shaper_init(2.84f, 0.05f, POSITION_LOOP_DT);

    // 轨迹规划 (速度 加速度 加加速度 Ts)
    s_curve_planner_init(&g_pos_planner, 5000.0f, 1000.0f, 1000.0f, POSITION_LOOP_DT);
    #endif
    
    #if FLUX_OBSERVER_ENABLE
    // 初始化磁链观测器
    flux_observer_init(&g_flux_obs);
    #endif

    #if HFI_ENABLE
    hfi_observer_init(&g_hfi_obs, HFI_INJECT_VOLTAGE);
    hfi_pll_init(&g_hfi_pll, HFI_PLL_KP, HFI_PLL_KI);
    #endif
    
    #if 0   // 电机零位校准时启用
    LL_TIM_EnableIT_CC4(TIM8);
    foc_ctrl.out_q = 0.5f; // 初始q轴电压
    //  将电角度设为90度(直接当作驱动电机角度)锁定电机至零位
    float sin_theta, cos_theta;
    CORDIC_SinCos_Deg(90.0f, &sin_theta, &cos_theta);
    inv_park_transform_f32(&foc_ctrl, &alpha_beta, sin_theta, cos_theta);
    svpwm.sector = svpwm_sector_calc(&alpha_beta);
    svpwm_calc_times(&alpha_beta, &svpwm, foc_voltage_data.vbus);
    svpwm_duty_calc(&svpwm);
    bsp_pwm_set_duty_three_phase(svpwm.pwm_a, svpwm.pwm_b, svpwm.pwm_c);
    HAL_Delay(2000); // 等待电机稳定
    debug_log("%f", encoder_data.mechanical_angle);
    #endif

    #if FOC_PARAMETER_IDENTIFICATION_ENABLE // 电机参数自辨识启用
    foc_motor_param_ident_start(1.0f, 0.5f, 600.0f, 0.1f, 0.05f);
    #endif
}

/**
 * @brief FOC外环控制主函数 1kHZ运行
 */
void foc_control(void)
{
    #if FOC_RESONANCE_ENABLE
    static uint16_t count = 0;
    float iq_fb;
    switch(g_res_test.state) {
        case 1:
            g_res_test.start_pos = encoder_data.mechanical_angle;
            
            if(count < 1000)
            {
                count ++;
                foc_ctrl.target_position = encoder_data.mechanical_angle;   // 稳定一段时间
                // 保持位置
                iq_fb = foc_position_pid_calculate(foc_ctrl.target_position, 
                                                        encoder_data.mechanical_angle);
                float theta = deg2rad(encoder_data.mechanical_angle);
                float iq_grav = 2.8f * sinf(theta - MOTOR_LOW);
                foc_ctrl.target_q = iq_fb + iq_grav;
            }
            else
            {
                 // 触发阶跃
                foc_ctrl.target_position = g_res_test.start_pos + g_res_test.target_step;
                g_res_test.sample_cnt = 0;
                g_res_test.print_idx = 0;
                g_res_test.state = 2;
            }
        break;
            
        case 2: // 记录中（弱控制）
            // 弱位置环
            iq_fb = foc_position_pid_calculate(foc_ctrl.target_position, 
                                                     encoder_data.mechanical_angle);
            float theta = deg2rad(encoder_data.mechanical_angle);
            float iq_grav = 2.8f * sinf(theta - MOTOR_LOW);
            foc_ctrl.target_q = iq_fb + iq_grav;
            
            // 记录数据（索引检查）
            if (g_res_test.sample_cnt < 500) {
                g_res_test.pos_data[g_res_test.sample_cnt] = encoder_data.mechanical_angle;
                g_res_test.iq_data[g_res_test.sample_cnt] = foc_ctrl.target_q;
                g_res_test.sample_cnt++;
                
                // 1000ms后完成
                if (g_res_test.sample_cnt >= 500) {
                    g_res_test.state = 3;
                    // 恢复位置环参数
                    foc_position_pi_init(POSITION_P_GAIN, POSITION_I_GAIN, 
                                       POSITION_D_GAIN, POSITION_I_LIMIT);
                }
            }
        break;
            
        case 3: // 完成，等待打印
            g_res_test.print_idx ++;
            if(g_res_test.print_idx < 500)
            {
                debug_log("%d,%.4f,%.4f", 
                        g_res_test.print_idx,
                        g_res_test.pos_data[g_res_test.print_idx],
                        g_res_test.iq_data[g_res_test.print_idx]);
            }
            else
            {
                g_res_test.state = 4;
            }
            foc_ctrl.target_q = 0.0f;
        break;
    }
    #endif
    
    #if FOC_COGGING_COMPENSATION_ENABLE
    // 滤波iq
    static ButterworthLPF_t filt;
    static float iq_filt;
    static uint8_t filt_inited = 0;
    
    // 初始化滤波器
    if (!filt_inited) {
        butterworth_init(&filt, 200.0f, SPEED_LOOP_TIME);
        filt_inited = 1;
    }
    iq_filt = butterworth_filter(&filt, foc_ctrl.abc_dq.current_q);
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

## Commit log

2025-12-08 添加初始代码及文档介绍
    [电机座子.SLDASM, 电机转接器.SLDPRT, 编码器板.SLDPRT]
2025-12-24 添加编码器读取
    [电机座子.SLDASM, 电机转接器.SLDPRT, 电机驱动板连接器.SLDPRT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]
2025-12-30 添加电机控制状态机
2026-01-08 添加降阶龙伯格观测器及梯形轨迹规划
    [测试负载连杆.SLDPRT, 电机座子.SLDASM, 电机驱动板连接器.SLDPRT]
2026-01-19 电机测试台架结构添加
    [台架底座.SLDPRT, 测试台架装配体.SLDASM, 测试负载连杆.SLDPRT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]
2026-01-21 更新第二代硬件版本代码及优化FOC核心中断处理效率
2026-02-14 非线性磁链观测器更新
2026-02-25 更新轨迹规划，输入整形部分
2026-03-01 常规更新
2026-03-04 CAN通信验证通信
2026-03-12 更新CANFD上位机运动学控制
2026-03-13 添加MIT控制段
2026-03-21 更新README
2026-03-21 修改README
2026-03-24 更改三阶状态观测器提取角速度及角角加速度
2026-03-26 更新第三关节
